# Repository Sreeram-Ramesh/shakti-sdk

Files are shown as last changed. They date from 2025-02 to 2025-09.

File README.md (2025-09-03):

# SHAKTI-Based Robotic Sorting Arm





A 4-DOF robotic arm that autonomously sorts objects by color, controlled by a SHAKTI RISC-V SoC running on a Nexys Video FPGA. This project was developed for the DIR-V 2025 National Hackathon and won **RUNNERS UP** in their flagship **48-hour hardware hackathon** winning us a cash prise of **Rs. 35000**. It showcases a minimalist and efficient approach to robotic automation through clever sensor integration and mechanical design.

### Collaborators

* [Ajitessh R](https://github.com/ElectronicExplorer) 
* [Sreeram R](https://github.com/Sreeram-Ramesh)
* [Vineeth Roshan Premanand](https://github.com/VineethRoshanP)

## Key Features

* **RISC-V Control:** Utilizes the open-source SHAKTI C-Class SoC as the central processing unit for all logic, control, and I/O operations.
* **Dual-Function Sensing:** A single APDS-9960 sensor is used for both object proximity detection (to guide the arm) and color identification (R, G, B), significantly reducing component count and firmware complexity.
* **Vacuum Suction Gripper:** Employs a vacuum-based gripper instead of a traditional mechanical claw. This results in a lighter, faster, and more reliable design with fewer actuators and failure points.

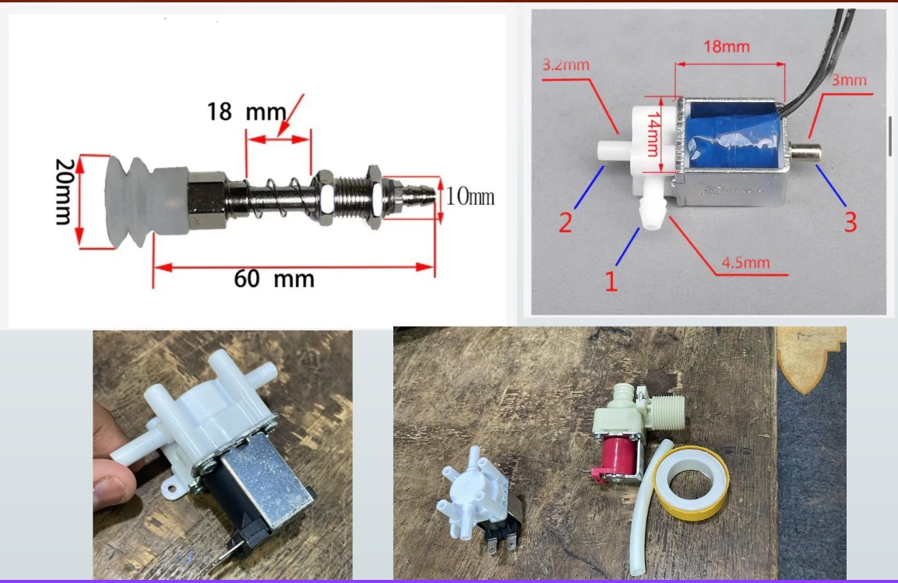
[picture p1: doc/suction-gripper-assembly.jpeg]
Suction assembly
<br>

* **Custom PCB Controller:** Features a custom-designed 2-layer PCB to cleanly integrate all sensors, servo motors, and power circuits with the main FPGA board.

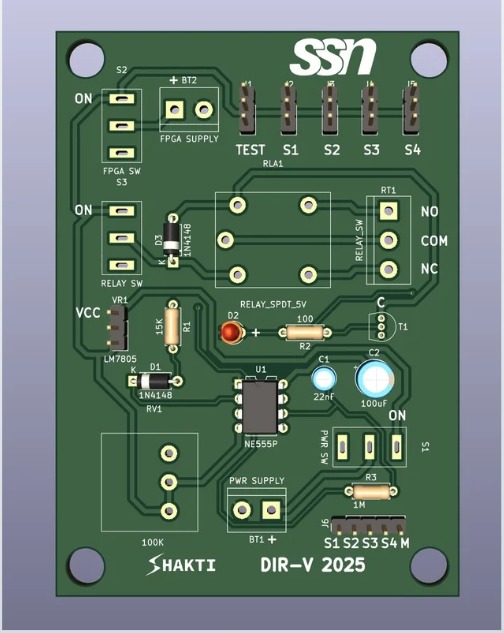
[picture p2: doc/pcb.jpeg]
PCB
<br>

## System Architecture

The system is a multi-disciplinary design combining custom mechanical parts, electronic hardware, and bare-metal firmware.

### 1. Mechanical Design

The arm is a 4-DOF (Degrees of Freedom) assembly driven by servo motors. The end-effector is a custom-designed vacuum suction gripper, chosen for its simplicity and speed over a mechanical alternative.

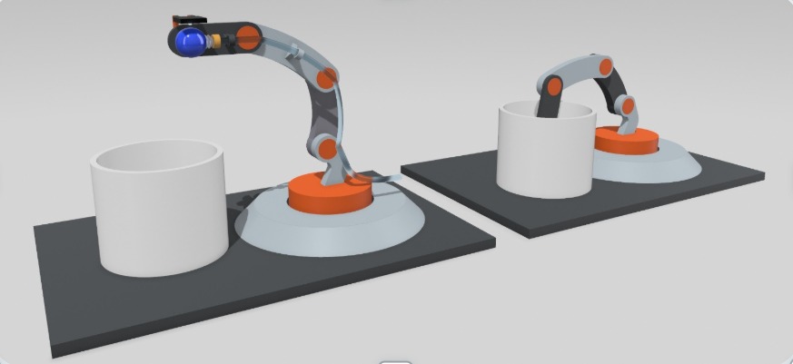
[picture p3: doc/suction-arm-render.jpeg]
Mechanical Render
<br>

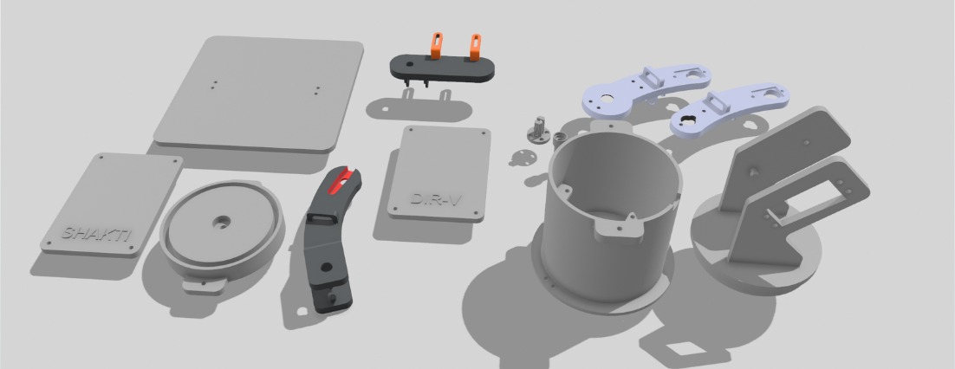
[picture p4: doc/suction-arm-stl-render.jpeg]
Stl file render
<br>

---

### 2. Hardware & Electronics

The electronic system is centered around the Nexys Video FPGA board, which hosts the SHAKTI SoC. A custom PCB acts as an interface shield for all external components.

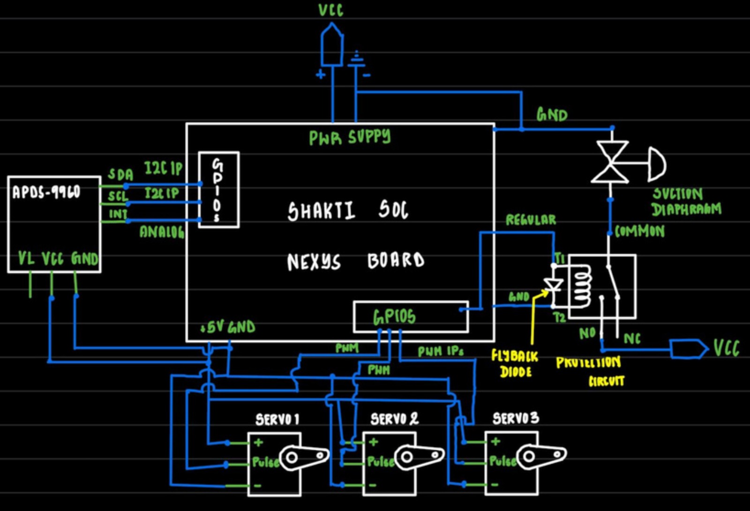
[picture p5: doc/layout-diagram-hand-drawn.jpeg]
Layout Diagram
<br>

* **FPGA Board:** Nexys Video (Xilinx Artix-7)
* **Processor:** SHAKTI C-Class RISC-V SoC
* **Sensor:** APDS-9960 (I2C interface) for proximity and color
* **Actuators:** MG995 and MG90S Servo Motors (PWM control)
* **Gripper:** Kamoer Diaphragm Pump controlled via a relay circuit

---

### 3. Firmware & Logic

The control application is a bare-metal C program developed using the SHAKTI SDK. The software is responsible for the entire operational flow, from scanning for objects to final placement.

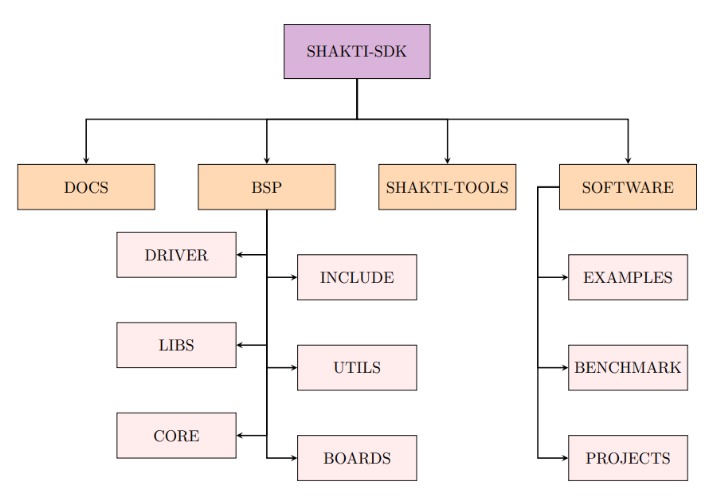
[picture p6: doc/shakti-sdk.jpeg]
Shakti SDK
<br>

The core algorithm performs the following steps:
1.  **Scan:** Executes a pre-programmed "Area Sweep Maneuver" to scan the collection bin for objects using the proximity sensor.
2.  **Approach & Pick:** Upon detecting an object, the arm positions the gripper and activates the vacuum pump.
3.  **Identify:** While the object is held, the APDS-9960 sensor determines its color.
4.  **Sort:** The arm rotates to the corresponding bin for the identified color.
5.  **Release:** The vacuum is released, dropping the ball.
6.  **Repeat:** The arm returns to the scanning maneuver until the bin is empty.

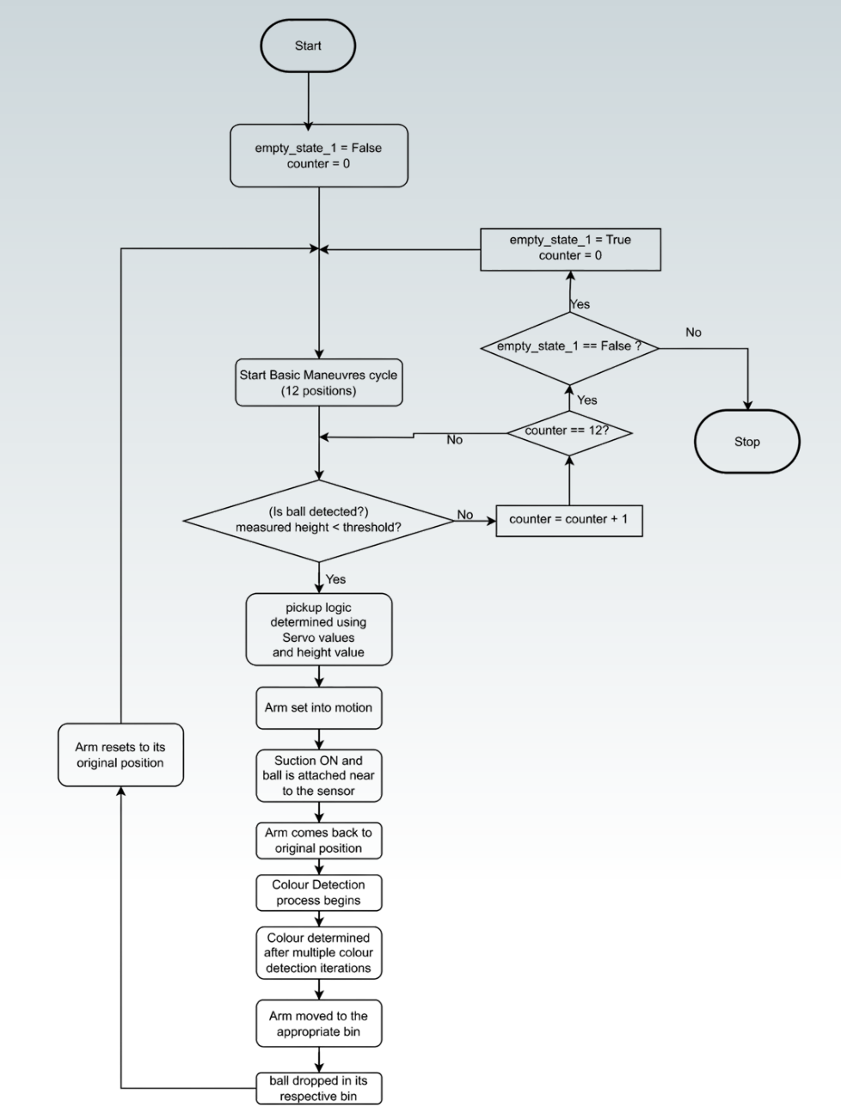
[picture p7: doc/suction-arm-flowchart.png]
<br>

---

### SHAKTI SDK Build and Deploy Workflow

This guide outlines the steps to compile a C application using the SHAKTI SDK, and then load and execute it on the SHAKTI C-Class Core running on the Nexys Video FPGA.

### Prerequisites

1.  **SHAKTI SDK:** You require to clone the official SDK and add custom application code is located in the `i2c_applns`, `pwm_applns` and `pwmv2_applns` directory, to the `software/examples` of the main shakti-sdk.
2.  **RISC-V Toolchain:** The `riscv64-unknown-elf` toolchain is to be installed and in your system's PATH.
3.  **OpenOCD:** OpenOCD is to be installed and configured for the Nexys Video board.
4.  **Hardware:** The FPGA is programmed with the correct SHAKTI C-Class bitstream.

---

### Step 1: Start the Debug Server (OpenOCD)

This command starts the Open On-Chip Debugger, which creates a GDB server that acts as a bridge between your computer and the JTAG interface of the SHAKTI core on the FPGA.

1.  Open a new terminal.
2.  Navigate to the board support package directory:
    ```shell
    cd shakti-sdk/bsp/third_party/shaktiz
    ```
3.  Run OpenOCD with the correct configuration file:
    ```shell
    sudo $(which openocd) -f ftdi.cfg
    ```
4.  If successful, OpenOCD will be listening for connections. **Do not close this terminal.**

---

### Step 2: Build the Software Application

This step compiles your C code into an executable RISC-V binary (`.shakti` file).

1.  Open a **second terminal**.
2.  Navigate to the main SDK directory:
    ```shell
    cd /path/to/your/shakti-sdk
    ```
3.  Run the `make` command, specifying your application and the target SoC.
    * `PROGRAM`: The path to your application's C file relative to `software/examples/`.
    * `TARGET`: The target SoC, which is `shaktiz` for this setup.

    **Example for your Robotic Arm project:**
    ```shell
    make software PROGRAM=pwmmotor_v2/RoboticArm TARGET=shaktiz
    ```
4.  Verify that the build was successful by checking the `output` directory. It should contain three files: `.dump`, `.o`, and `.shakti`.

---

### Step 3: Load and Run the Code (GDB)

This step uses the RISC-V GNU Debugger (GDB) to connect to the OpenOCD server, load your compiled program into the FPGA's memory, and start its execution.

1.  In the same terminal as Step 2, launch the debugger:
    ```shell
    riscv64-unknown-elf-gdb
    ```
2.  Inside the GDB prompt, run the following commands in sequence.

    ```gdb
    # Set a long timeout to prevent connection issues
    set remotetimeout 240

    # Connect to the OpenOCD server running on your machine
    target remote :3333

    # Load your compiled application's symbols and code
    # NOTE: You load the .shakti file, NOT the .c file.
    file software/examples/pwmmotor_v2/RoboticArm/output/RoboticArm.shakti
    load

    # Continue execution (run the program)
    c
    ```
Your program is now running on the SHAKTI Core.

---

### Creating a New Project (Case 2)

To create a new application, the simplest method is to:
1.  Copy an existing example folder (e.g., `gpio`) that is similar to your needs.
2.  Rename the folder and the `.c` file inside to match your new project name.
3.  Modify the `Makefile` inside that directory, changing the `src` and `exe` variables to your new project name.

---

### Demonstration at the final evaluation at the end of 48-hrs

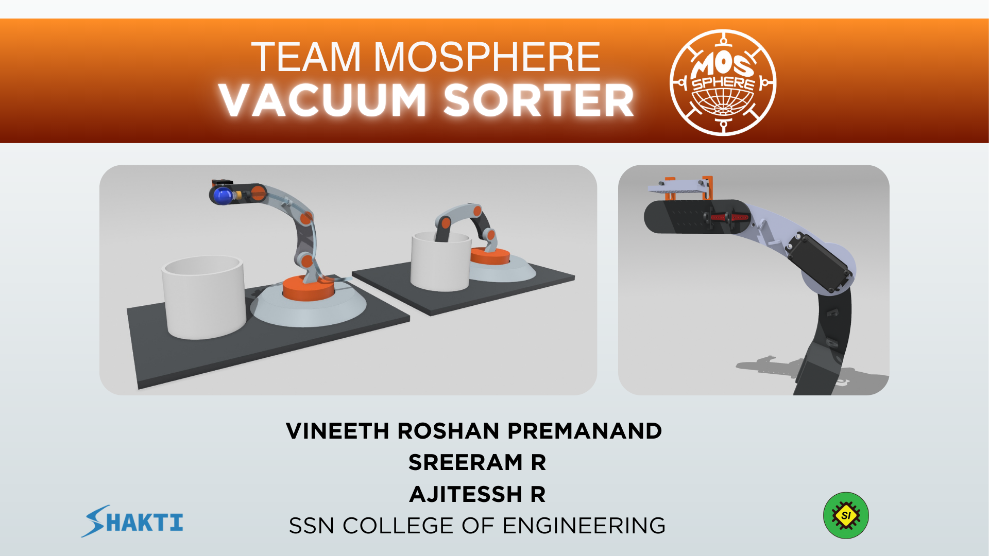
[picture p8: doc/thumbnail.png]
Robotic Arm Demo (https://www.youtube.com/watch?v=qiLszU0Jg18)


---

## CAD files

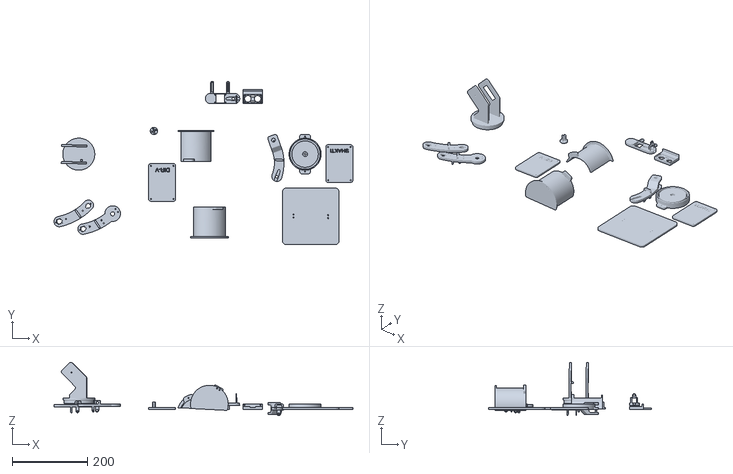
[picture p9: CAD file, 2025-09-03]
stl/FinalPrintFile v8.stl
792.7 x 433.1 x 140.9

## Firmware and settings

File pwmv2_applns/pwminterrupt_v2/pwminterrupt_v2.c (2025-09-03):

/***************************************************************************
* Project           		: shakti devt board
* Name of the file	     	: pwminterrupt_v2.c
* Brief Description of file     : Control an led with the help of a button, gpio based.
* Name of Author    	        : Soutrick Roy Chowdhury
* Email ID                      : soutrickofficial@gmail.com

 Copyright (C) 2019  IIT Madras. All rights reserved.

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
***************************************************************************/

/**
@file pwminterrupt_v2.c
@brief example file to make the different pwminterrupt 
@detail It will make the interrupt after a certain frequency
*/

#include "pwmv2.h"
#include "plic_driver.h"
#include "gpiov2.h"
#define PWM_0 0

void handle_pwm_interrupt( uint32_t num)
{
	gpiov2_init();
	gpiov2_instance->direction = 0x10000;
	gpiov2_instance->toggle = 0x10000;

    pwm_set_control((6-num),0x80);
	log_info("pwm interrupt handled\n");
}

int main()
{

	printf("\n====================================================\n");

    register unsigned int retval;
	int i;

	plic_init();

	/*
	   Configure pwm module interrupt
	*/
	configure_interrupt(PLIC_INTERRUPT_6);

	/* For checking PWM Interrupt by toggling one board LED */
	// isr_table[PLIC_INTERRUPT_6] = handle_pwm_interrupt;

	/* For checking all the test case*/
	isr_table[PLIC_INTERRUPT_6] = pwm_isr_handler0;


	/**we need to set the period, duty cycle and the clock divisor in order
	 *to set it to the frequency required. Base clock is 50MHz
	 **/
	asm volatile("li      t0, 8\t\n"
			"csrrs   zero, mstatus, t0\t\n"
		    );

	asm volatile("li      t0, 0x800\t\n"
			"csrrs   zero, mie, t0\t\n"
		    );

	asm volatile("csrr %[retval], mstatus\n"
			:
			[retval]
			"=r"
			(retval)
		    );

	log_info("mstatus = %x\n", retval);
	asm volatile("csrr %[retval], mie\n"
			:
			[retval]
			"=r"
			(retval)
		    );

	log_info("mie = %x\n", retval);

	asm volatile("csrr %[retval], mip\n"
			:
			[retval]
			"=r"
			(retval)
		    );

	log_info("mip = %x\n", retval);


    check_pwmv2();
	/* Enable when need rise interrupt */
#if 1	
	pwm_init();
    pwm_set_prescalar_value(PWM_0, 0xf2);
 	pwm_configure(PWM_0, 0xff, 0x01, rise_interrupt, 0x1, false);
    pwm_start(PWM_0);
	pwm_show_values(PWM_0);
    pwm_set_control(PWM_0, (PWM_ENABLE | PWM_UPDATE_ENABLE |PWM_OUTPUT_ENABLE | PWM_RISE_INTERRUPT_ENABLE | PWM_OUTPUT_POLARITY ));
#endif

	/* Enable when fall interrupt */
#if 0
	pwm_init();
    pwm_set_prescalar_value(PWM_0, 0xf2);
 	pwm_configure(PWM_0, 0xff, 80, fall_interrupt, 0x1, false);
    pwm_start(PWM_0);
	pwm_show_values(PWM_0);
    pwm_set_control(PWM_0, (PWM_ENABLE | PWM_UPDATE_ENABLE |PWM_OUTPUT_ENABLE | PWM_FALL_INTERRUPT_ENABLE | PWM_OUTPUT_POLARITY ));
#endif

	/* Enable when halfperiod_interrupt  */
#if 0
	pwm_init();
    pwm_set_prescalar_value(PWM_0, 0xf2);
 	pwm_configure(PWM_0, 0xff, 80, halfperiod_interrupt, 0x1, false);
    pwm_start(PWM_0);
	pwm_show_values(PWM_0);
    pwm_set_control(PWM_0, (PWM_ENABLE | PWM_UPDATE_ENABLE |PWM_OUTPUT_ENABLE | PWM_HALFPERIOD_INTERRUPT_ENABLE | PWM_OUTPUT_POLARITY ));
#endif

	/* Uncomment for checking Output Disable with PWM Interrupt */
#if 0
	pwm_init();
    pwm_set_prescalar_value(PWM_0, 0xf2);
 	pwm_configure(PWM_0, 0xff, 0x01, rise_interrupt, 0x1, false);
    pwm_start(PWM_0);
	pwm_show_values(PWM_0);
    pwm_set_control(PWM_0, (PWM_ENABLE | PWM_UPDATE_ENABLE | PWM_RISE_INTERRUPT_ENABLE | PWM_OUTPUT_POLARITY ));
#endif

	while(1);
    return 0;
}

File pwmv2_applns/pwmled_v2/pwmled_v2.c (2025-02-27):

/***************************************************************************
* Project               	        	:  shakti devt board
* Name of the file	            	    :  pwmled_v2.c
* Brief Description of file             :  example file for pwm led.
* Name of Author    	                :  Soutrick Roy Chowdhury
* Email ID                              :  soutrickofficial@gmail.com
 Copyright (C) 2019  IIT Madras. All rights reserved.

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
***************************************************************************/
/**
@file pwmled.c
@brief example file to make the led blink at specified frequency
@detail it runs the led and causes it to blink at specified frequency using the pwm module
*/

#include "pwmv2.h"
#include "pinmux.h"
#include <stdio.h>

#define PWM_0 0
#define PWM_1 1 
#define PWM_2 2 
#define PWM_3 3
#define PWM_4 4 
#define PWM_5 2

/** @fn int main()
 * @brief main function that runs the code
 * @return zero
 */
int main()
{
	check_pwmv2();
	//*pinmux_config_reg = 0x2aa80;
	pwm_init();

	//Uncomment this for testing PWM 0
	pwm_set_prescalar_value(PWM_0, 5000);
	pwm_clear(PWM_0);
	pwm_stop(PWM_0);
	pwm_configure(PWM_0, 10000, 5000, no_interrupt, 0x1, false);
	pwm_start(PWM_0);
	pwm_set_control(PWM_0, (PWM_ENABLE | PWM_UPDATE_ENABLE |PWM_OUTPUT_ENABLE | PWM_OUTPUT_POLARITY ));
	pwm_show_values(PWM_0);
	pwm_show_frequency(PWM_0, 5000, 10000);

	//Uncomment this for testing PWM 1
	pwm_set_prescalar_value(PWM_1, 5000);
	pwm_clear(PWM_1);
	pwm_stop(PWM_1);
	pwm_configure(PWM_1, 10000, 5000, no_interrupt, 0x1, false);
	pwm_start(PWM_1);
	pwm_set_control(PWM_1, (PWM_ENABLE | PWM_UPDATE_ENABLE |PWM_OUTPUT_ENABLE | PWM_RISE_INTERRUPT_ENABLE | PWM_OUTPUT_POLARITY ));
	pwm_show_values(PWM_1);
	pwm_show_frequency(PWM_1, 5000, 10000);

	//Uncomment this for testing PWM 2
	pwm_set_prescalar_value(PWM_2, 5000);
	pwm_clear(PWM_2);
	pwm_stop(PWM_2);
	pwm_configure(PWM_2, 10000, 5000, no_interrupt, 0x1, false);
	pwm_start(PWM_2);
	pwm_set_control(PWM_2, (PWM_ENABLE | PWM_UPDATE_ENABLE |PWM_OUTPUT_ENABLE | PWM_RISE_INTERRUPT_ENABLE | PWM_OUTPUT_POLARITY ));
	pwm_show_values(PWM_2);
	pwm_show_frequency(PWM_2, 5000, 10000);

	//Uncomment this for testing PWM 3
	pwm_set_prescalar_value(PWM_3, 5000);
	pwm_clear(PWM_3);
	pwm_stop(PWM_3);
	pwm_configure(PWM_3, 10000, 5000, no_interrupt, 0x1, false);
	pwm_start(PWM_3);
	pwm_set_control(PWM_3, (PWM_ENABLE | PWM_UPDATE_ENABLE |PWM_OUTPUT_ENABLE | PWM_RISE_INTERRUPT_ENABLE | PWM_OUTPUT_POLARITY ));
	pwm_show_values(PWM_3);
	pwm_show_frequency(PWM_3, 5000, 10000);


	//Uncomment this for testing PWM 4
	pwm_set_prescalar_value(PWM_4, 5000);
	pwm_clear(PWM_4);
	pwm_stop(PWM_4);
	pwm_configure(PWM_4, 10000, 5000, no_interrupt, 0x1, false);
	pwm_start(PWM_4);
	pwm_set_control(PWM_4, (PWM_ENABLE | PWM_UPDATE_ENABLE |PWM_OUTPUT_ENABLE | PWM_RISE_INTERRUPT_ENABLE | PWM_OUTPUT_POLARITY ));
	pwm_show_values(PWM_4);
	pwm_show_frequency(PWM_3, 5000, 10000);


	//Uncomment this for testing PWM 5
	pwm_set_prescalar_value(PWM_5, 5000);
	pwm_clear(PWM_5);
	pwm_stop(PWM_5);
	pwm_configure(PWM_5, 10000, 5000, no_interrupt, 0x1, false);
	pwm_start(PWM_5);
	pwm_set_control(PWM_5, (PWM_ENABLE | PWM_UPDATE_ENABLE |PWM_OUTPUT_ENABLE | PWM_RISE_INTERRUPT_ENABLE | PWM_OUTPUT_POLARITY ));
	pwm_show_values(PWM_5);
	pwm_show_frequency(PWM_5, 5000, 10000);



	//Uncomment this for testing PWM 0 as disabling output 
	pwm_set_prescalar_value(PWM_0, 50000);
	pwm_clear(PWM_0);
	pwm_stop(PWM_0);
	pwm_configure(PWM_0, 0xf0, 0x80, no_interrupt, 0x1, false);
	pwm_start(PWM_0);
	pwm_set_control(PWM_0, (PWM_ENABLE | PWM_UPDATE_ENABLE | PWM_OUTPUT_POLARITY ));
	pwm_show_values(PWM_0);
	pwm_show_frequency(PWM_0, 50000, 0xf0);
	return 0;
}

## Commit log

2021-07-27 Uart1 Interrupt code
2025-09-03 Updated with final resources
    [FinalPrintFile v8.stl]

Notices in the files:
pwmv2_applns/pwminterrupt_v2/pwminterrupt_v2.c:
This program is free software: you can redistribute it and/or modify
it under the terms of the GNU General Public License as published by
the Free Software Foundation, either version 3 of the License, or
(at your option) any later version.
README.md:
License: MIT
